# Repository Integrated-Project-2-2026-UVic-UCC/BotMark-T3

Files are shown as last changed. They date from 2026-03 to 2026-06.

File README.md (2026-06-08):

<h1 align="center">🌱🤖Automated Line-Painting Robot🤖🌱</h1>

<p align="center"> A mechatronics engineering project focused on the precise marking of grass fields using an autonomous robot </p>
<div align="center">
   
</div>

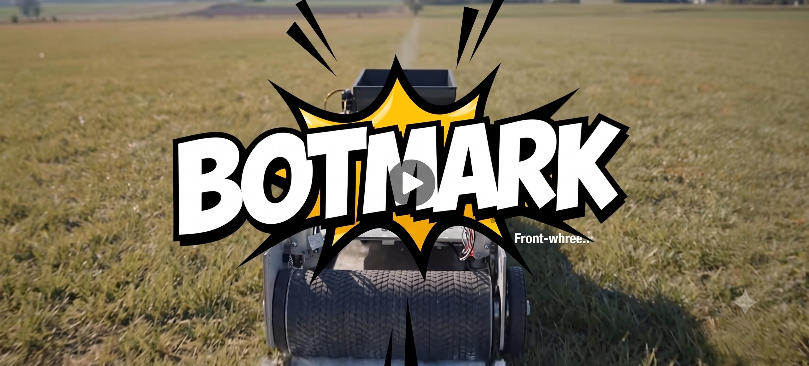
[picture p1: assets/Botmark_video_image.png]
difermon09 | GitHub


## 📌Introduction:
Field marking in football pitches is a time-consuming and precision-critical task. Traditional methods require manual measurement, steady handling, and several hours of labor.

Our bussiness, BOTMARK, proposes the design and development of a reduced-scale autonomous robot capable of navigating a football field and painting regulation-compliant lines using integrated positioning, sensing, and control systems.<br>


The goal is to combine:
- Mechanical robustness  
- Accurate dispensing mechanisms  
- Autonomous path execution  

## 🏅Objectives:
The main objective is to design and build a prototipe of an autonomous robotic platform capable of marking the lines of a grass field with high precision and minimal human intervention. The prototipe is indoor and with sand instead of paint.

### Specific Goals
To achieve this, the following requirements have to be fulfill:
| Feature | Description |
|---|---|
| 🔍 Localization | Integration of reliable positioning systems (Odometry + IMU + Lidar) |
| 🛞 Mobility & Storage | Chassis suitable for indoor use and storage to do a line of 2m |
| ⚡Electronics | To power and connect all the components|
| 🎯 Precision | Precise paint application mechanism |
| 🤖 Autonomy | Automated painting sequences up to 40 min |
| 📱 Manage | Mobile application for supervision |

## 📁 Repository Structure

<details>
  <summary>🖼️ <b>assets</b></summary>
  <ul>
    <li>Contains all the <b>media</b> and <b>images</b> for the this README.</li>
  </ul>
</details>

<details>
  <summary>💡 <b>electronics</b></summary>
  <ul>
    <li>Contains all the electronic circuit designs, <b>PCB layouts</b>, <b>Schematics</b>, and <b>Gerber files</b> necessary for board manufacturing.</li>
  </ul>
</details>

<details>
  <summary>🔩 <b>mechanics</b></summary>
  <ul>
    <li>Contains the mechanical plans, source <b>CAD files</b>, and ready-to-print <b>STL files</b> for the chassis, wheels, and sand funnel mechanisms.</li>
  </ul>
</details>

<details>
  <summary>📱 <b>web_app</b></summary>
  <ul>
    <li>Contains the application code for the <b>user interface</b> and remote supervision of the robot.</li>
  </ul>
</details>

<details>
  <summary>🤖 <b>robot_coding</b></summary>
  <ul>
    <li>Central repository containing the complete codebase for the autonomous robot, from low-level microcontroller firmware to high-level ROS 2 navigation and networking.</li>
  </ul>
  
  <blockquote>
  <details>
    <summary>👾 <b>firmware</b> <i>(ESP32)</i></summary>
    <ul>
      <li>ESP32 PlatformIO project containing the low-level C/C++ programming.</li>
      <ul>
      <li><b>lib/:</b> Custom libraries for hardware control (Encoders, IMU, Kinematics, Motors, PID, Zenoh).</li>
      <li><b>src/:</b> Main execution loop (<code>main.cpp</code>).</li>
      </ul>
    </ul>
  </details>

  <details>
    <summary>🧠 <b>ros2_ws</b> <i>(High-Level Logic & ROS 2)</i></summary>
    <ul>
      <li>ROS 2 workspace responsible for high-level processing, autonomous navigation, sensor data handling, and DDS communication.</li>
      <ul>
        <li><b>mission_manager/:</b> Python package handling navigation sequences. Includes a <code>config/</code> folder with the route YAML.</li>
        <li><b>controller_pkg/:</b> C++ package for managing the robot's control loop and odometry.</li>
        <li><b>ldlidar_stl_ros2/:</b> Node driver for the Lidar sensor (<a href="https://github.com/ldrobotSensorTeam/ldlidar_stl_ros2.git" target="_blank">provided by manufacturer</a>).</li>
        <li><b>obstacle_detector/:</b> C++ package for Lidar data processing and collision avoidance.</li>
        <li><b>zenoh_bridge/:</b> C++ package for DDS communication with the microcontroller.</li>
        <li><b>robot_bringup/:</b> Python package containing the launch file (<code>launch/robot_core.launch.py</code>) to start the entire system.</li>
      </ul>
    </ul>
  </details>

  <details>
    <summary>🔌 <b>udev & zenoh_router</b></summary>
    <ul>
      <li><b>udev/:</b> Linux rules (<code>99-robot.rules</code>) for stable USB sensor and motor connections.</li>
      <li><b>zenoh_router_v1.8.0/:</b> Router setup and configuration for Zenoh communications.</li>
    </ul>
  </details>
  </blockquote>
</details>

<details>
  <summary>⚙️ <b>Environment Setup</b></summary>
  <ul>
    <li><b>setup_env.sh:</b> Bash script to quickly configure the development environment and dependencies.
</details>

## 🛠️ Bill of Materials (BOM)

| 📸 Image | Component | Quantity | Current Unit Price [€] | Current Cost [€] | Provider |
| :---: | :--- | ---: | ---: | ---: | :--- |
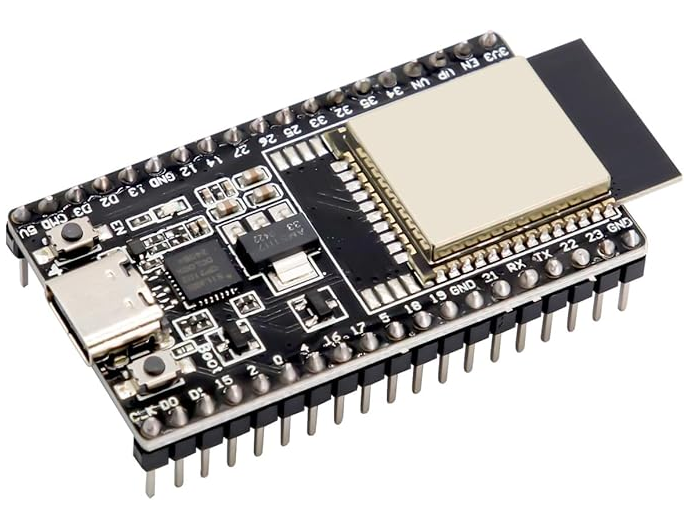
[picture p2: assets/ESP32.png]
|  | ESP32 | 1 | 13.99 | 13.99 | <a href="https://www.amazon.es/-/en/Diymore-Nodemcu-Development-NodeMCU-Bluetooth/dp/B0D9BTQRYT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" target="_blank"> Amazon </a> |
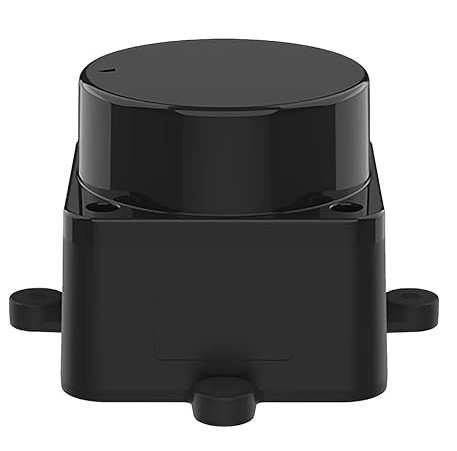
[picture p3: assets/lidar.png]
|  | Lidar sensor | 1 | 71.99 | 71.99 | <a href="https://www.amazon.es/-/en/Kit-12m-Distance-Intelligent-Manufacturer/dp/B0B1VD2PJH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" target="_blank"> Amazon </a> |
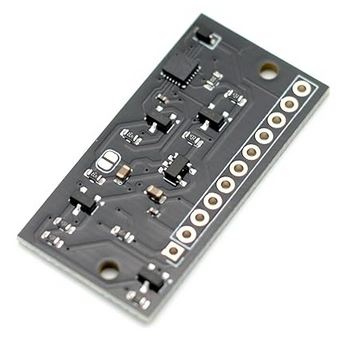
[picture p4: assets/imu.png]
|  | IMU ICM-20948 | 1 | 12.87 | 12.87 | <a href="https://www.amazon.es/-/en/Minflora-S6O8295TO4805BSRUM39I50V6/dp/B0H35S3NCC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" target="_blank"> Amazon </a> |
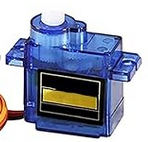
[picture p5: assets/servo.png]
|   | 90g Servomotor | 1 | 2.2 | 2.2 | <a href="https://www.amazon.es/-/en/Walking-Helicopter-Airplane-Vehicle-Compatible/dp/B0F1CQTQ31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" target="_blank"> Amazon </a> |
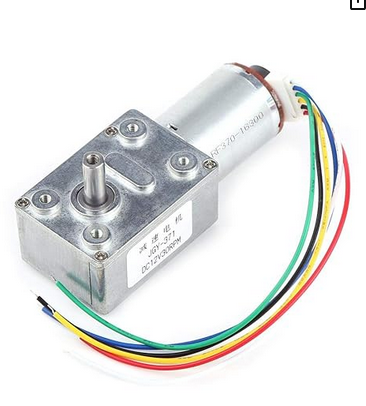
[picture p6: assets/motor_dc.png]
|  | DC Motors with encoders | 2 | 21.5 | 43 | <a href="https://www.amazon.es/turbina-schneckengetriebemotor-Encoder-Incluso-Bloqueo/dp/B07J2J2NGB?th=1" target="_blank"> Amazon </a> |
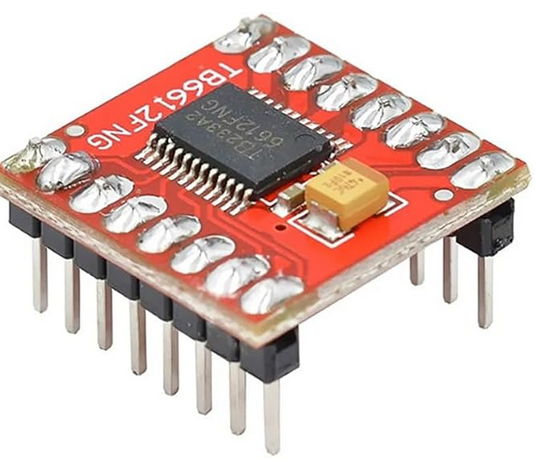
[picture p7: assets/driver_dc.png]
|  | DC Motor Driver TB6612FNG| 1 | 1.25 | 1.25 | <a href="https://www.amazon.es/iHaospace-TB6612FNG-Stepper-Driver-Controller/dp/B0CQCMPYXJ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" target="_blank"> Amazon </a> |
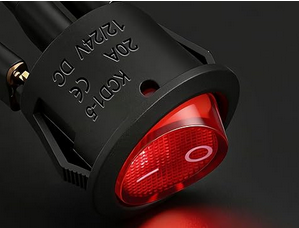
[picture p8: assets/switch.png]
|  | Switch | 1 | 1.3 | 1.3 | <a href="https://www.amazon.es/Heschen-SPST-Interruptor-basculante-terminales/dp/B07G22DZ2N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" target="_blank"> Amazon </a> |
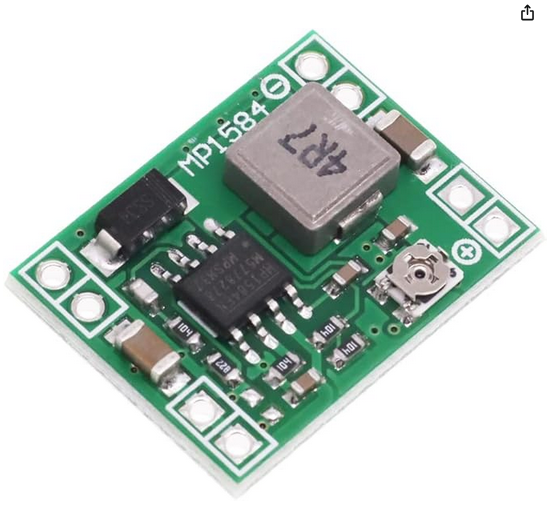
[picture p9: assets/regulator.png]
|  | Current regulator MP1584EN | 2 | 1.25 | 2.5 | <a href="https://www.amazon.es/HENGBIRD-buck-converter/dp/B0GYX25J36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" target="_blank"> Amazon </a> |
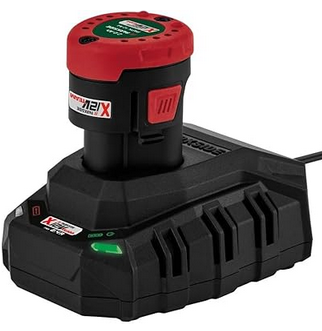
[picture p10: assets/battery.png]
|  | 12V Drill battery | 2 | 20.99 | 41.98 | <a href="https://www.amazon.es/Bater%C3%ADa-extra-para-herramientas-familia/dp/B07SGPYZDK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" target="_blank"> Amazon </a> |
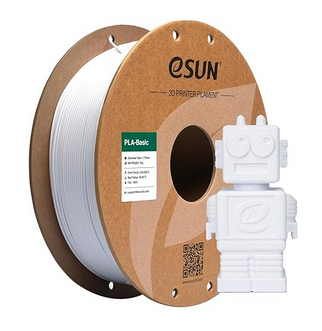
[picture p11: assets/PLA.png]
|  | 1Kg PLA | 1 | 11.72 | 11.72 | <a href="https://www.amazon.es/-/en/eSUN-Filament-Dimensional-Accuracy-Printers/dp/B0CR1DBBFM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" target="_blank"> Amazon </a> |
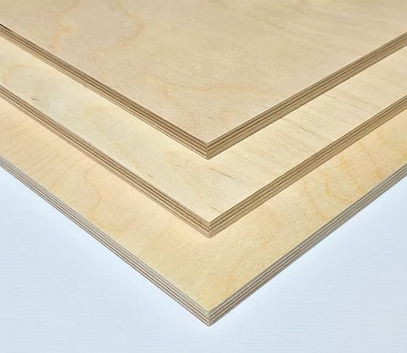
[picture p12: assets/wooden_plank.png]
|  | 50x50cm Wooden plank | 1 | 16.26 | 16.26 | <a href="https://www.amazon.es/-/en/AtHaus%C2%AE-Plywood-Multiplex-Boards-Available/dp/B0DF2N84ZW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" target="_blank"> Amazon </a> |
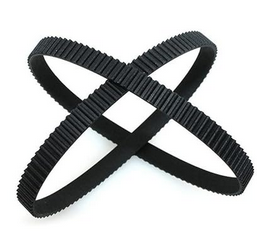
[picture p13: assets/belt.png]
|  | Timing belt | 2 | 5.33 | 10.66 | <a href="https://www.amazon.es/dp/B0CQQXWH6B?th=1" target="_blank"> Amazon </a> |
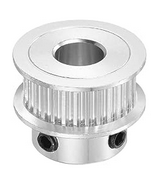
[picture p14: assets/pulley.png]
|  | Belt pulley | 2 | 5.25 | 10.49 | <a href="https://www.amazon.es/QUARKZMAN-Dentada-Temporizaci%C3%B3n-Aluminio-Hexagonal/dp/B0DRBM9TG1" target="_blank"> Amazon </a> |
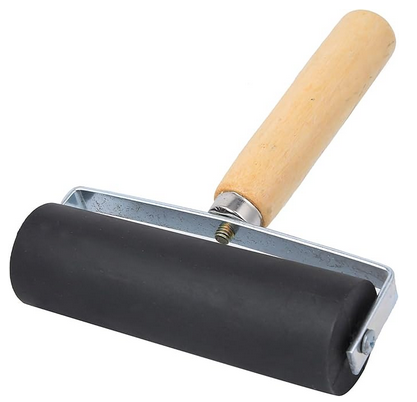
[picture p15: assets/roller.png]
|  | Hard rubber roller | 1 | 11.41 | 11.41 | <a href="https://www.amazon.es/dp/B0D7CWNKWM" target="_blank"> Amazon </a> |
| | | | **Total cost** | **251.62** | |

## 🧾 Software Dependencies
<ul>
  <li><b>Operating System:</b> Ubuntu 22.04 LTS (Jammy Jellyfish).</li>
  <li><b>Robotics Framework:</b> ROS 2 Humble.</li>
  <li><b>Firmware IDE:</b> Visual Studio Code with the <b>PlatformIO</b> extension.</li>
  <li><b>Languages:</b> C++ and Python 3.10</li>
  <li><b>Networking:</b> Eclipse Zenoh (Router v1.8.0 is included directly in the repository).</li>
</ul>

<blockquote>
  <p><b>💡 Note:</b> All the other dependencies will be installed automatically at the Software & Firmware Setup paragraph</p>
</blockquote>

## 🏗️ Hardware Assembly (DIY Guide)
For the wiring, follow the electrical scheme of the electronics
## 💻 Software & Firmware Setup
<p>This repository is structured to make the initial setup fast and automated. The codebase is divided into three main environments: the high-level robot layer (ROS 2), the microcontroller firmware (ESP32), and the web app interface.</p>

### ROS 2 Environment and UDEV Rules (Linux)
<p>At the root of the project, you will find an automation script (<code>setup_env.sh</code>). This script automatically downloads the missing ROS 2 dependencies using <code>rosdep</code> and installs the system's UDEV rules (strictly necessary to assign the fixed ports <code>/dev/lidar</code> and <code>/dev/esp32</code>).</p>

<p>Open a terminal at the root of the project and run:</p>

<pre><code>chmod +x setup_env.sh
./setup_env.sh</code></pre>

<p>Once the script finishes successfully, build the ROS 2 workspace to generate the binaries and source the installation:</p>

<pre><code>cd robot_coding/ros2_ws
colcon build</code>
source install/setup.bash</code></pre>

### Microcontroller Firmware (ESP32)
<p>The low-level code is fully managed with PlatformIO, so there is no need to manually search for or install C++ libraries.</p>

<ol>
  <li>Open the <code>robot_coding/firmware</code> folder using Visual Studio Code (requires having the official PlatformIO extension installed).</li>
  <li>Upon opening the project, PlatformIO will read the configuration and automatically download all necessary dependencies in the background (PID management, Zenoh bridge, motor libraries, etc.).</li>
   <li>Change the Wifi credentials to yours</li>
  <li>Connect the ESP32 board to your PC via USB and use the <b>Upload</b> button on the bottom bar of PlatformIO to build and flash the code onto the microcontroller.</li>
</ol>

### App Web Interface

## 🚀 How to Run (Usage)
<p>Once the initial setup and firmware flashing are complete, you can start the entire robot ecosystem by following these steps.</p>

### Start the Robot Core (ROS 2)
<p>Ensure your ESP32 and LiDAR are connected via USB. Open a terminal, source your workspace, and execute the main launch file. This single command orchestrates all the nodes and the zenoh router:</p>

<pre><code>cd robot_coding/ros2_ws
source install/setup.bash
ros2 launch robot_bringup robot_core.launch.py</code></pre>

<p>You should see the terminal output confirming that the LiDAR communication is normal and the Zenoh router is successfully connected to the microcontroller.</p>

### Shutdown
<p>To safely stop the robot, simply press <code>Ctrl + C</code> in the terminal running the ROS 2 launch file. The system will automatically shut down all nodes, stop the motors, and close the Zenoh connections.</p>

## <picture></picture> Development Status
### 🚩Current Phase: Finished🚩
<p>The vast majority of the objectives proposed at the beginning of the project have been successfully achieved, delivering a structured and functional robotic ecosystem. However, to maintain transparent documentation, the following points should be considered for future iterations:</p>

### 🛠️ Hardware Limitations (Known Issues)
<ul>
  <li><b>Rear wheel fastening:</b> There is a mechanical design flaw that causes one of the rear wheels to unscrew during continuous turns. It is highly recommended that the client or the mechanical team redesign the fastening system (e.g., by adding nylon locknuts or using reverse threading) for the next prototype.</li>
</ul>

### 🚀 Future Work & Improvements (Roadmap)
<p>Due to time constraints, the drift correction system—which was intended to fuse raw odometry, IMU data, and LiDAR triangulation with beacons using an <b>Extended Kalman Filter (EKF)</b>—was not implemented.</p>

<p><b>Why is this not a blocker?</b><br>
This omission does not affect the client's final scope. The current triangulation system was designed exclusively for the <b>indoor</b> prototype. The final product version will require a complete architectural shift regardless, in order to integrate <b>outdoor</b> positioning systems (such as GPS/RTK).</p>

<blockquote>
  <p><b>⚠️ Technical Note for Future Developers:</b><br>
  Once the project is resumed and the Kalman Filter (EKF) is implemented to correct the drift, it is vital to update the subscriptions within the <code>controller_node</code>. Currently, the control logic relies on raw odometry. This must be updated so the node subscribes to the newly filtered odometry topic (typically <code>/odometry/filtered</code>).</p>
</blockquote>

##  Team

- Project Manager – Oriol Arbonies  
- Mechanical Lead – Àlex López  
- Electronics Lead – Joan Marc Tur  
- Software Lead – Dídac Fernández -> <a href="https://github.com/difermon09" target="_blank">difermon09 | GitHub </a>

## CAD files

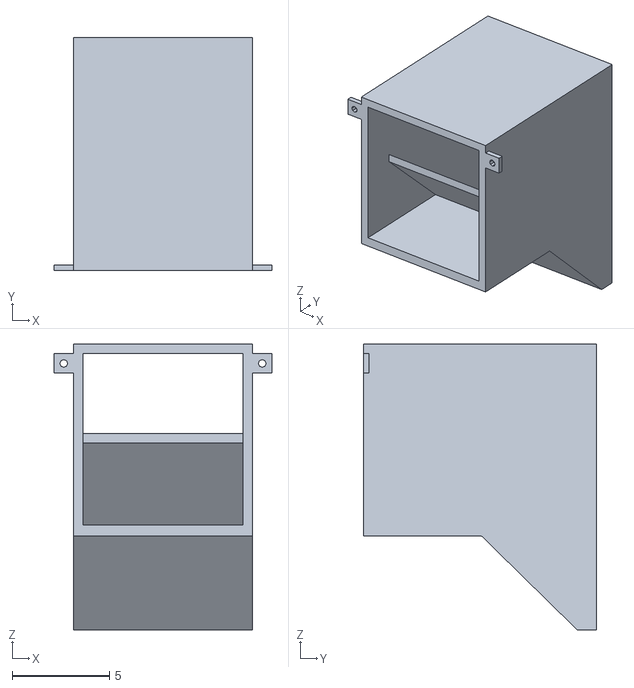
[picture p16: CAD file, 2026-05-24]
mechanics/funnelsandv5.stl
11.2 x 12.0 x 14.7

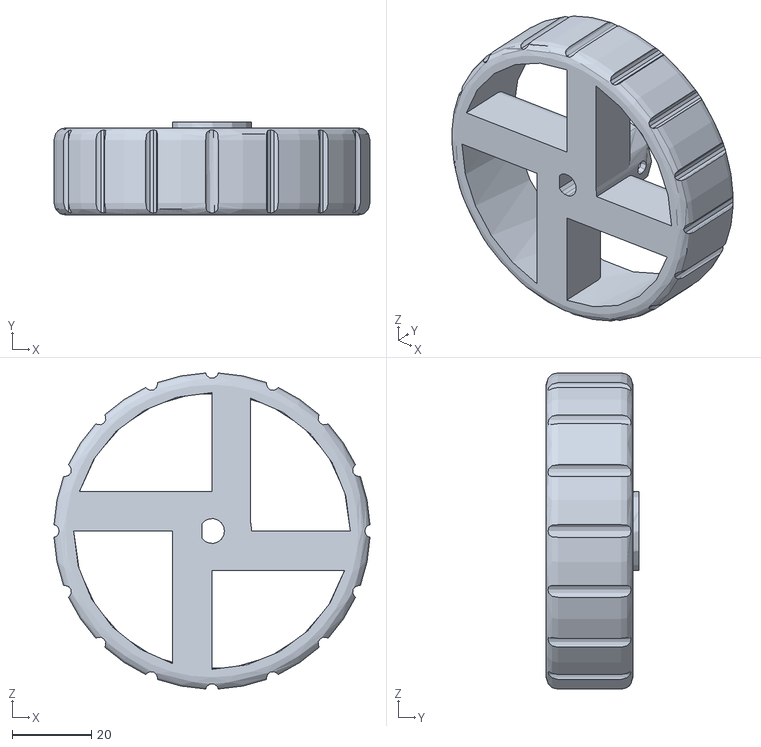
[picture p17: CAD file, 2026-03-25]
mechanics/Wheel.stl
79.9 x 23.5 x 79.9

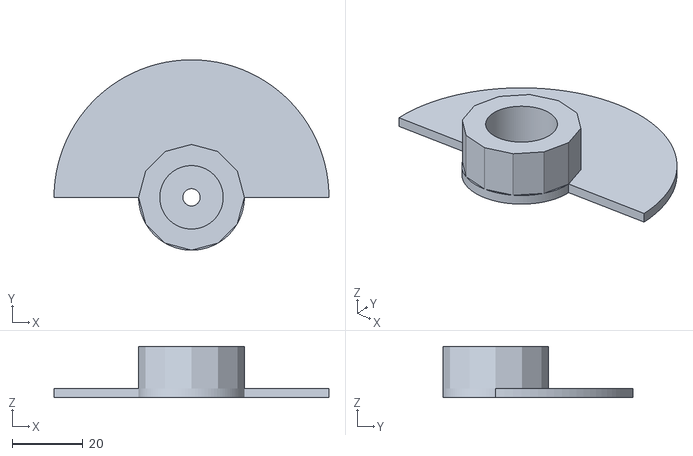
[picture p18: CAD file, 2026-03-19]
mechanics/ServoDamper-Rotor.stl
78.0 x 54.0 x 14.5

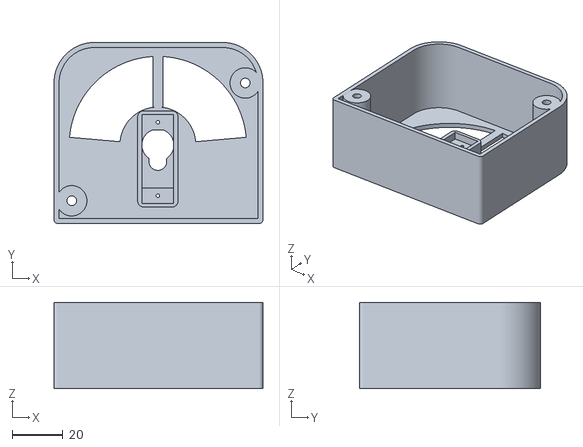
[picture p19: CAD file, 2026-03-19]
mechanics/ServoDamper-Box.stl
82.5 x 71.5 x 34.0

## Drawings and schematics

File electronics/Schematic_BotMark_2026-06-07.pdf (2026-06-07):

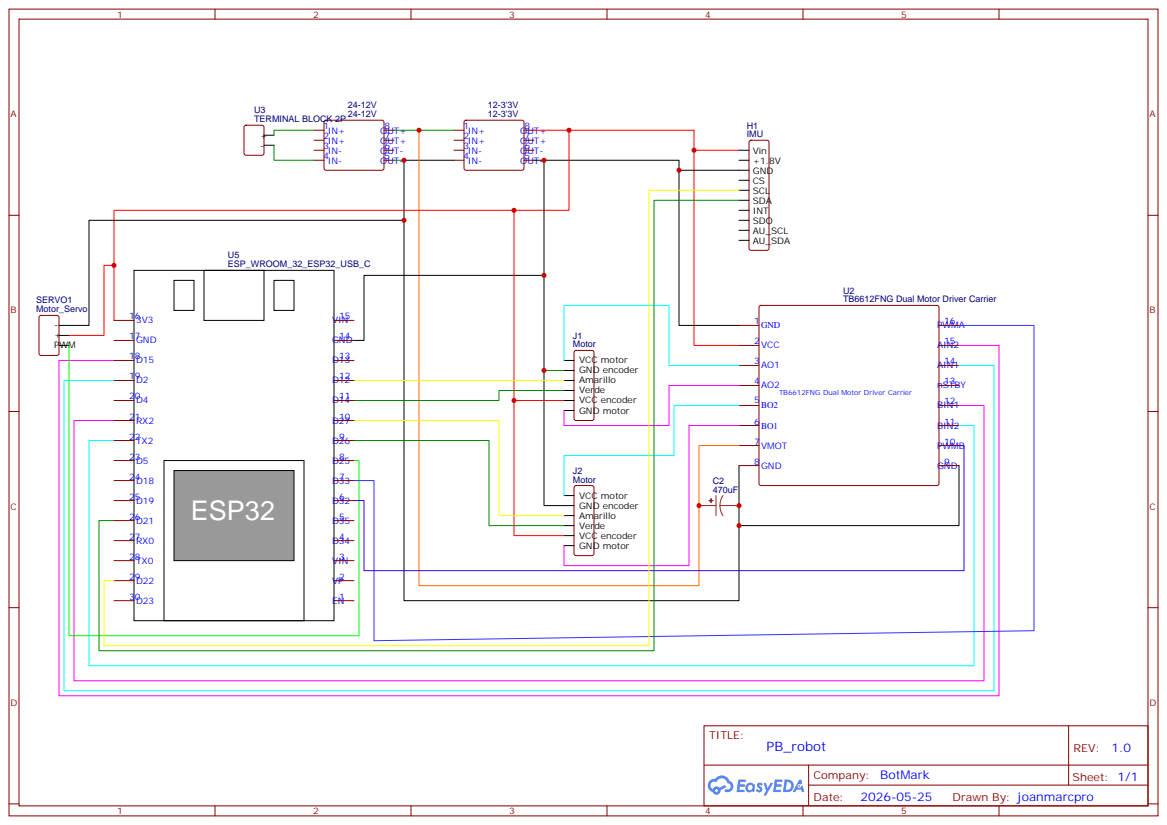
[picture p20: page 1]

TB6612FNG Dual Motor Driver Carrier

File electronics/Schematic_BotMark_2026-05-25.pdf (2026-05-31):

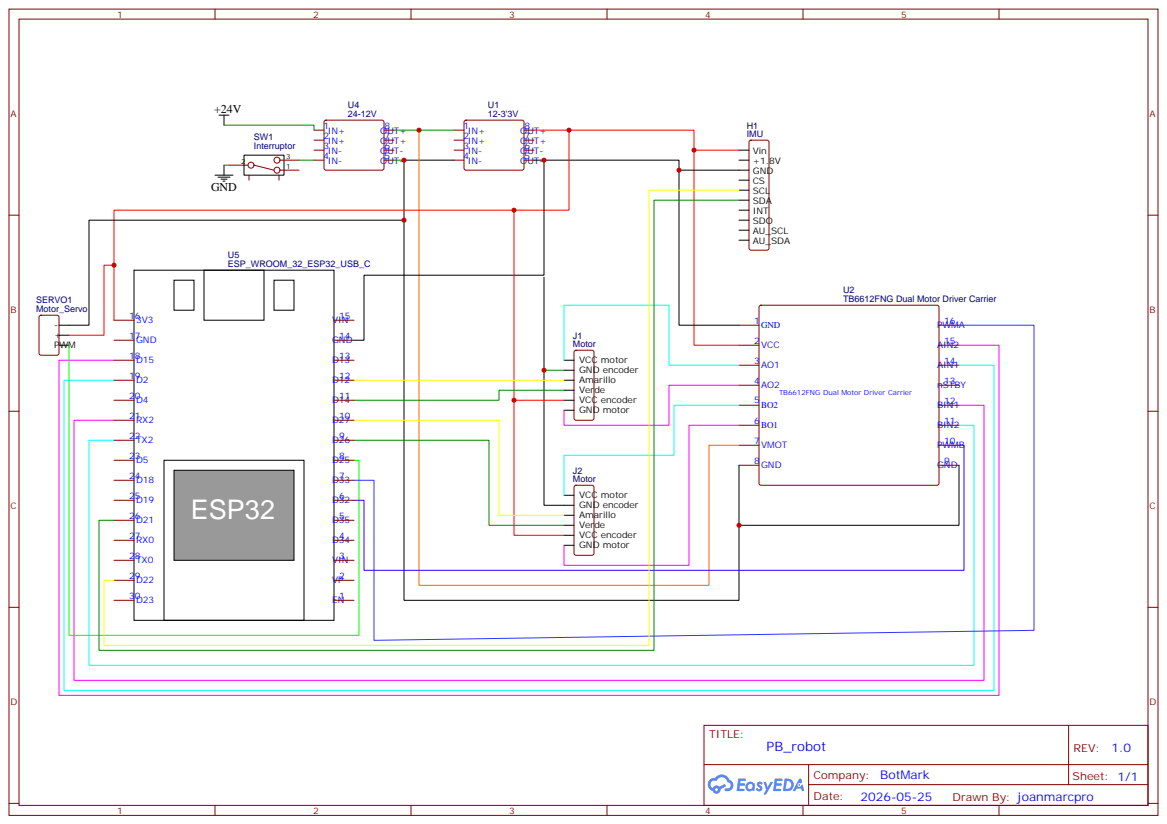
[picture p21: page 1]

TB6612FNG Dual Motor Driver Carrier

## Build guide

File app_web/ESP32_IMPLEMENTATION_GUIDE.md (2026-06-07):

# ESP32 Wi-Fi Robot Control Implementation Guide

This document explains how to use the web interface we just built, how to host it so you can access it from your phone, and provides an exact example of the code you need to flash onto your ESP32.

---

## 1. Hosting the Web App on Your Computer

To use this application from your mobile phone, both your computer and your phone must be connected to the **same Wi-Fi network**.

1. Open **VS Code**.
2. Install the extension called **"Live Server"** (by Ritwick Dey) if you don't have it already.
3. Open the `index.html` file in VS Code.
4. Click **"Go Live"** in the bottom right corner of VS Code (or right-click the HTML file and select "Open with Live Server").
5. Your computer will start a local web server (usually at `http://127.0.0.1:5500/index.html`).

---

## 2. Accessing the Web App from Your Phone

1. Find your computer's local IP address on your Wi-Fi network. 
   - On Windows, open the Command Prompt and type `ipconfig`. Look for the "IPv4 Address" (e.g., `192.168.1.50`).
2. Open the web browser on your smartphone.
3. Type in your computer's IP address and the Live Server port. For example:
   `http://192.168.1.50:5500/index.html`
4. You should now see the premium robot control interface on your phone!

---

## 3. Programming the ESP32 (Using the Custom Library)

The web interface sends HTTP requests to the ESP32. To make the code clean and easy to manage, we have created a custom C++ library called `RobotWebControl` inside the `esp32_library` folder.

This library hides the complex Wi-Fi setup and CORS (Cross-Origin Resource Sharing) security requirements so you can just focus on programming your robot's motors.

### How the Library Works

The library consists of two main files (`RobotWebControl.h` and `RobotWebControl.cpp`) that wrap the standard `WebServer` and `WiFi` libraries. It provides simple "callbacks" (functions that run when an event happens). You just tell it what to do when a "START", "STOP", "PAUSE", or "RESUME" command arrives!

### Arduino IDE Example

Open the `esp32_library.ino` file inside the `esp32_library` folder in your Arduino IDE. It looks like this:

```cpp
#include "RobotWebControl.h"

// Initialize the library
RobotWebControl robotControl;

// Replace with your Wi-Fi credentials
const char* ssid = "YOUR_WIFI_SSID";
const char* password = "YOUR_WIFI_PASSWORD";

void setup() {
  Serial.begin(115200);

  // 1. Define what happens when the web app sends a "START" command
  robotControl.onStart([]() {
    Serial.println("Action: Starting Robot Routine...");
    // TODO: Add your motor start code here
  });

  // 2. Define what happens when the web app sends a "STOP" command
  robotControl.onStop([]() {
    Serial.println("Action: Emergency Stop!");
    // TODO: Add your motor stop code here
  });

  // 3. Define what happens when the web app sends a "PAUSE" command
  robotControl.onPause([]() {
    Serial.println("Action: Pausing Robot...");
    // TODO: Add your motor pause code here
  });

  // 4. Define what happens when the web app sends a "RESUME" command
  robotControl.onResume([]() {
    Serial.println("Action: Resuming Robot...");
    // TODO: Add your motor resume code here
  });

  // Start the Wi-Fi and Web Server
  robotControl.begin(ssid, password);
}

void loop() {
  // Listen for incoming web requests (Required to keep the server responsive)
  robotControl.handleClient();
  
  // Other robot logic (sensors, movement, etc.) can go here!
}
```

### Steps to implement this:
1. Open the `esp32_library.ino` file in the Arduino IDE. Ensure the `RobotWebControl.h` and `RobotWebControl.cpp` files are in the same folder.
2. Replace `YOUR_WIFI_SSID` and `YOUR_WIFI_PASSWORD` with your actual Wi-Fi network details (the same one your computer and phone are connected to).
3. Add your specific motor control code inside the callback blocks (e.g., inside the `robotControl.onStart([]() { ... });` block).
4. Upload the code to your ESP32.
5. Open the **Serial Monitor** (at 115200 baud rate).
6. Wait for it to connect and copy the **ESP32 IP Address** printed in the Serial Monitor.
7. Open the Web App on your phone, paste that IP address at the top, and click **"Set"**.

The connection indicator should turn green and start pulsing, and clicking the buttons will trigger your custom code and print the commands in your Serial Monitor!

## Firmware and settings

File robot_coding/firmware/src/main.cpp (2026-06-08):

// This program implements the main control loop for an autonomous robot, integrating 
// hardware interfaces, kinematic calculations, PID control, and network communications 
// via a web application and the Zenoh protocol.

#include <Arduino.h>

#include <motors_controller.h>
#include <encoder_handler.h>
#include <imu_manager.h>
#include <kinematics.h>
#include <pid_controller.h>
#include <web_app_controller.h>
#include <zenoh_manager.h>
#include <ESP32Servo.h>

#include "config.h"
#include "secrets.h"

// Hardware configuration mapping
MotorHW hw_left = {Pin::M_LEFT_IN1, Pin::M_LEFT_IN2, Pin::M_LEFT_PWM};
MotorHW hw_right = {Pin::M_RIGHT_IN1, Pin::M_RIGHT_IN2, Pin::M_RIGHT_PWM};

EncoderConfig enc_left = {Pin::ENC_LEFT_A, Pin::ENC_LEFT_B};
EncoderConfig enc_right = {Pin::ENC_RIGHT_A, Pin::ENC_RIGHT_B};

RobotPhysics robot_physics = {Phys::WHEEL_DIAMETER, Phys::PPR, Phys::GEAR_RATIO}; 

// Subsystem instances
Servo servo;
MotorsController motorsController(hw_left, hw_right);
EncoderHandler encoderHandler(enc_right, enc_left, robot_physics); 
IMUManager imuManager;
Kinematics kinematicsManager(Phys::WHEEL_TRACK); 
PIDController pidYaw(PID::YAW_KP, PID::YAW_KI, PID::YAW_KD, PID::YAW_MIN, PID::YAW_MAX);
PIDController pidLeft(PID::LEFT_KP, PID::LEFT_KI, PID::LEFT_KD, PID::LEFT_MIN, PID::LEFT_MAX);
PIDController pidRight(PID::RIGHT_KP, PID::RIGHT_KI, PID::RIGHT_KD, PID::RIGHT_MIN, PID::RIGHT_MAX);
WebAppController webAppServer(80);
ZenohManager zenohManager;

// State and timing variables
unsigned long last_control_time = 0;
unsigned long last_zenoh_time = 0;
bool is_stopped = false; 
bool is_paused = false;

// Web application callback functions
void HandleStop() {
    is_stopped = true;
    zenohManager.publishStopped(true);
    Serial.println("State: STOP");
}

void HandleStart() {
    is_stopped = false;
    zenohManager.publishStopped(false);
    
    // Reset PID controllers on startup to prevent sudden jumps
    servo.write(ServoAngles::CLOSE_ANGLE);
    pidLeft.reset();
    pidRight.reset();
    Serial.println("State: START");
}

void HandlePause() {
    is_paused = true;
    zenohManager.publishPaused(true);
    Serial.println("State: PAUSE");
}

void HandleResume() {
    is_paused = false;
    zenohManager.publishPaused(false);
    Serial.println("State: RESUME");
}

void setup() {
    Serial.begin(115200);
    
    // Initialize physical hardware subsystems
    ESP32PWM::allocateTimer(3);
    servo.setPeriodHertz(50);
    servo.attach(Pin::SERVO);
    servo.write(ServoAngles::CLOSE_ANGLE);

    motorsController.begin();
    encoderHandler.begin();
    
    // Initialize IMU with connection retries
    Serial.print("Connecting IMU");
    while (!imuManager.begin(Pin::IMU_SDA, Pin::IMU_SCL)) {
        Serial.print(".");
        delay(500);
    }
    
    Serial.println("\nIMU initialized successfully");
    Serial.println("Keep the robot steady to calibrate zero heading...");
    delay(2000); 
    imuManager.resetYaw();
    Serial.println("Yaw reset to 0");

    // Bind callback functions to the web server and initialize network
    webAppServer.onStop(HandleStop);
    webAppServer.onStart(HandleStart);
    webAppServer.onPause(HandlePause);
    webAppServer.onResume(HandleResume);
    webAppServer.begin(Network::SSID, Network::PASSWORD);

    // Initialize Zenoh communication manager with connection retries
    Serial.print("Connecting Zenoh");
    while (!zenohManager.begin(Network::ROUTER_IP)) { 
        Serial.print(".");
        delay(300);
    }
    Serial.println("\nZenoh Manager initialized successfully");
}

void loop() {
    // Continuously listen for incoming web application commands
    webAppServer.handleClient();
    
    unsigned long current_time = millis();

    // Execute core control loop based on defined timing interval
    if (current_time - last_control_time >= Timing::CONTROL_TIME_MS) {
        float delta_time = (current_time - last_control_time) / 1000.0;
        encoderHandler.update(delta_time);
        imuManager.update();

        float current_yaw = imuManager.getYawRad();

        // Safety check to halt movement if stopped, paused, or blocked
        if (is_stopped || is_paused || zenohManager.isObstacleDetected()) {
            servo.write(ServoAngles::CLOSE_ANGLE);
            motorsController.move(0, 0);
            pidLeft.reset();
            pidRight.reset();
            pidYaw.reset(current_yaw);
        } else {

            Twist command = zenohManager.getLastCommand();
            
            // Calculate yaw correction and final wheel speeds
            // float corrected_angular_z = command.angular_z + pidYaw.circularCompute(command.angular_z, current_yaw, delta_time);
            // WheelSpeeds target_speeds = kinematicsManager.calculateWheelSpeeds(command.linear_x, corrected_angular_z);

            // // Compute PWM outputs via individual wheel PID controllers
            // int out_left = (int)pidLeft.linealCompute(target_speeds.left, encoderHandler.getVelocityLeft(), delta_time);
            // int out_right = (int)pidRight.linealCompute(target_speeds.right, encoderHandler.getVelocityRight(), delta_time);
            // servo.write(ServoAngles::OPEN_ANGLE);
            // motorsController.move(out_left, out_right);
            
            WheelSpeeds target_speeds = kinematicsManager.calculateWheelSpeeds(command.linear_x, command.angular_z);
            servo.write(ServoAngles::OPEN_ANGLE);
            motorsController.move(target_speeds.left, target_speeds.right);
        }

        last_control_time = current_time;
    }

    // Transmit telemetry data based on defined timing interval
    if (current_time - last_zenoh_time >= Timing::TELEMETRY_TIME_MS) {
        if (zenohManager.isConnected()) {
            SensorData sensor_data;
            
            // Capture current encoder counts
            sensor_data.ticks_left = encoderHandler.getTicksLeft(); 
            sensor_data.ticks_right   = encoderHandler.getTicksRight();    
            
            // Capture current IMU readings
            sensor_data.accel_x = imuManager.getAccelX();         
            sensor_data.accel_y = imuManager.getAccelY();
            sensor_data.accel_z = imuManager.getAccelZ();
            sensor_data.gyro_x  = imuManager.getGyroX();
            sensor_data.gyro_y  = imuManager.getGyroY();
            sensor_data.gyro_z  = imuManager.getGyroZ();
            
            zenohManager.publishSensors(sensor_data);
        }

        last_zenoh_time = current_time;
    }
}

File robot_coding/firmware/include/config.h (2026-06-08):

// This header file defines the global configuration parameters for the robot,
// including hardware pin assignments, physical dimensions, PID controller 
// constants, and system timing intervals.

#pragma once

// Hardware pin assignments
namespace Pin {
    constexpr int M_LEFT_IN1 = 16, M_LEFT_IN2 = 17, M_LEFT_PWM = 32;
    constexpr int M_RIGHT_IN1 = 2, M_RIGHT_IN2 = 15, M_RIGHT_PWM = 33;
    constexpr int ENC_LEFT_A = 12, ENC_LEFT_B = 14; 
    constexpr int ENC_RIGHT_A = 26, ENC_RIGHT_B = 27;
    constexpr int IMU_SDA = 21, IMU_SCL = 22;
    constexpr int SERVO = 25;
}

// Mechanical properties and physical measurements
namespace Phys {
    constexpr float WHEEL_DIAMETER = 0.08f;
    constexpr float WHEEL_TRACK = 0.235f; 
    constexpr int PPR = 11;
    constexpr float GEAR_RATIO = 700.0f;
}

// Proportional-Integral-Derivative (PID) controller tuning parameters
namespace PID {
    // Left wheel PID constants and output limits
    constexpr float LEFT_KP = 0.5f, LEFT_KI = 0.1f, LEFT_KD = 0.05f;
    constexpr float LEFT_MIN = -255.0f, LEFT_MAX = 255.0f;

    // Right wheel PID constants and output limits
    constexpr float RIGHT_KP = 0.5f, RIGHT_KI = 0.1f, RIGHT_KD = 0.05f;
    constexpr float RIGHT_MIN = -255.0f, RIGHT_MAX = 255.0f;
    
    // Yaw orientation PID constants and output limits
    constexpr float YAW_KP = 2.0f, YAW_KI = 0.0f, YAW_KD = 0.1f;
    constexpr float YAW_MIN = -0.5f, YAW_MAX = 0.5f;
}

// Loop execution and telemetry transmission intervals
namespace Timing {
    constexpr int CONTROL_TIME_MS = 10;
    constexpr int TELEMETRY_TIME_MS = 100;
}

namespace ServoAngles {
    constexpr float CLOSE_ANGLE = 0.0f;
    constexpr float OPEN_ANGLE = 180.0f;
}

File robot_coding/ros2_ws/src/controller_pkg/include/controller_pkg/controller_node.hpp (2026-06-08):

// Header file defining the ControllerNode node for handling ROS 2 navigation actions,
// integrating odometry, obstacle detection, and issuing velocity commands.

#pragma once

#include <memory>
#include <thread>
#include <mutex>
#include <cmath>

#include <rclcpp/rclcpp.hpp>
#include <rclcpp_action/rclcpp_action.hpp> 
#include <nav2_msgs/action/navigate_to_pose.hpp>
#include <nav_msgs/msg/odometry.hpp>
#include <std_msgs/msg/bool.hpp>
#include <geometry_msgs/msg/twist.hpp>
#include <tf2/LinearMath/Quaternion.h>
#include <tf2/LinearMath/Matrix3x3.h>

using NavigateToPose = nav2_msgs::action::NavigateToPose;
using GoalHandleNavigate = rclcpp_action::ServerGoalHandle<NavigateToPose>;

class ControllerNode : public rclcpp::Node
{
public:
    ControllerNode();

private:
    // Operational state flags
    bool _is_paused = false;
    bool _is_stopped = false;

    // ROS 2 subscriptions, publishers, and action server
    rclcpp::Subscription<std_msgs::msg::Bool>::SharedPtr _pause_sub;
    rclcpp::Subscription<std_msgs::msg::Bool>::SharedPtr _stop_sub;
    rclcpp_action::Server<NavigateToPose>::SharedPtr _action_server;
    rclcpp::Subscription<nav_msgs::msg::Odometry>::SharedPtr _odom_sub;
    rclcpp::Subscription<std_msgs::msg::Bool>::SharedPtr _lidar_sub;
    rclcpp::Publisher<geometry_msgs::msg::Twist>::SharedPtr _cmd_vel_pub;

    // Internal state variables
    std::mutex _data_mutex; 
    double _current_x = 0.0;
    double _current_y = 0.0;
    double _current_yaw = 0.0;
    bool _has_odom = false;
    bool _obstacle_detected = false;

    // Kinematic control parameters and tolerances
    const double ACCEPTANCE_RADIUS = 0.25; 
    const double MAX_LINEAR_SPEED = 0.4;   
    const double MAX_ANGULAR_SPEED = 1.0;

    const double KP_LINEAR = 0.5;          
    const double KP_ANGULAR = 1.5;

    double _integral_error = 0.0;
    const double KI_LINEAR = 0.05;
    const double INTEGRAL_LIMIT = 0.2; 


    // Private utility and action handling methods
    double normalizeAngle(double angle);

    rclcpp_action::GoalResponse handleGoal(
        const rclcpp_action::GoalUUID & uuid,
        std::shared_ptr<const NavigateToPose::Goal> goal);

    rclcpp_action::CancelResponse handleCancel(
        const std::shared_ptr<GoalHandleNavigate> goal_handle);

    void handleAccepted(const std::shared_ptr<GoalHandleNavigate> goal_handle);

    void publishStop();

    void execute(const std::shared_ptr<GoalHandleNavigate> goal_handle);
};

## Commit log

2026-03-19 stl servo damper designed by the mechanical leed Àlex
    [ServoDamper-Box.stl, ServoDamper-Rotor.stl]
2026-03-25 Update electronics schemes
    [Wheel.stl]
2026-04-28 pin corrections
2026-04-29 Transfer PlatformIO, adapted IMU to MPU-9250, improve IMU and Kinematics libraries and add Zenoh comunication
2026-05-24 reorder and add new features
    [ServoDamper-Box.stl, ServoDamper-Rotor.stl, Wheel.stl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]
2026-05-24 remove repeated pieces
    [servorotor.stl, servorotorbox.stl]
2026-05-24 adaptar nueva imu
2026-06-07 Add Bill of Materials section to README
    Added a Bill of Materials (BOM) section to the README with details on components, quantities, prices, and providers.
2026-06-07 Fix item list and total cost label in README
    Updated item descriptions and corrected total cost label in the materials list.
2026-06-07 Revise README structure and add new sections
    Updated README to improve structure and clarity, added sections on software dependencies, hardware assembly, and usage instructions.
2026-06-07 Update Hardware Assembly section with wiring note
    Added note about wiring in the Hardware Assembly section.
2026-06-07 Clarify project objective and prototype details
    Updated the project objective to specify the prototype's indoor use and sand marking.
2026-06-08 udev esp32 rule added
2026-06-08 servo added
2026-06-08 servo added and testing
